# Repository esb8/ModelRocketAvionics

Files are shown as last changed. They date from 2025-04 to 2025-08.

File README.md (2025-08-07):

# Model Rocketry Flight Computer and Embedded Patch Antenna – Full PCB + Assembly

An open-source avionics system developed for **model rocketry** applications by the [Metropolitain Aerospace Rocket Society at Toronto Metropolitan University](https://marstmu.com/). Originally designed for FPV drones, this project has been adapted into a **flight computer** supporting GPS, sensor fusion, data logging, and telemetry, all within a compact, custom PCB. This board also features a **custom microstrip antenna** designed by [Javezki](https://github.com/Javezki). All schematics and KiCad 9.0 PCB design files are openly available.

---

## Overview

This project delivers a robust and flexible **flight computer** for **high-power G-80 model rockets**, built on the STM32F411CEU6 microcontroller. It provides modular avionics functionality—combining flight control, telemetry, power management rated for 1S-2S LiPo, and sensor integration—making it suitable for in-flight data acquisition, staging logic, and recovery system deployment.

---

## Hardware Overview

### **Integrated Flight Computer Design**
- **Flight Computer**: RP2040 
- **Power Regulation**: High-efficiency DC-DC converters (1S LiPo)
- **Telemetry**: Long-range LoRa communication
- **Sensor Suite**: Altitude, attitude, temperature, and pressure sensing

### **Interfaces & Expansion**
- SPI-connected sensor peripherals
- USB-C programming and data offloading
- JTAG/SWD debug support
- UART/FTDI interface for external modules
- Coin cell backup power for RTC
- GPS module for position logging

---

## Flight Computer Board Features

- **MCU**: RP2040 (100MHz ARM Cortex-M4)
- **Clock Source**: 12MHz external crystal
- **IMU**: ICM-42605 (gyro + accel)
- **Barometer**: BMP280 for altitude tracking
- **GNSS**: L86-M33 GPS module (GLONASS+GPS)
- **Telemetry**: SX1276 LoRa 915MHz transceiver (NiceRF)
- **Power**: USB-C input, LDOs, and external 3.3V support

---

## Power System (Planned for Rocket Integration)

- SWD Flash for in-field reprogramming
- High-efficiency DC-DC converters
- Battery support: 1-2S LiPo or custom packs
- Regulated 3.3V rail for sensitive components
- XT60 or JST input connector options

---

## Software Compatibility

- **BetaFlight** (legacy; for IMU prototyping)
- **Custom C/C++ Firmware** (recommended for real-time rocketry logic)

---

## Bill of Materials (Key Components)

| Component | Description | Specification |
|---|---|---|
| Frame | Enclosure/Avionics Bay | Custom 3D-printed or machined |
| MCU | STM32F411CEU6 | ARM Cortex M4 100MHz |
| GPS | L86-M33 | GNSS Positioning |
| IMU | ICM-42605 | 6DOF motion tracking |
| Barometer | BMP280 | Pressure & altitude sensor |
| Radio | SX1276 LoRa | 915MHz telemetry |
| Battery | LiPo / Rocket battery pack | 1S–2S supported via DC regulation |
| Connectors | USB-C, JST, XT60 | Power + Programming |
| Antenna | SMA 915MHz | Half-dipole LoRa |

---

## Tools & Assembly Requirements

- Soldering iron + fine solder
- Heat shrink tubing
- Multimeter & continuity tester
- LiPo battery charger (if applicable)
- Debug tools: ST-Link V2 / J-Link
- KiCad (PCB design and modification)
- Screws, standoffs, foam tape, zip ties

---

## Required Knowledge

- Soldering and PCB assembly
- STM32 microcontroller basics
- Familiarity with LoRa/telemetry systems
- Firmware flashing and serial debugging
- Understanding model rocketry avionics architecture

---

## Calculations

### Altimeter/Flight Timing Logic
- Barometer resolution: ±1 meter (BMP280)
- GPS fix interval: 1Hz–10Hz (L86-M33)
- IMU update: Up to 1kHz via SPI

### Power Budget
- MCU current draw: ~50mA
- LoRa TX Peak: ~120mA
- Sensors + GPS: ~30–50mA
- Total ~200–250mA @ 3.3V (0.7–1W typical)

---

## Testing & Validation

1. Flash microcontroller via SWD
2. USB-C serial communication verification
3. IMU and GPS data output test
4. Barometer altitude validation
5. LoRa telemetry range and signal integrity
6. Full ground simulation test (power cycling, resets)
7. Field tests (static fire or live launch)

---

## Media

### Flight Computer – 3D Model

### Flight Computer – PCB

### Flight Computer – Schematic


## Collaboration

This system is being developed by **Evan Bhogal** and **Javezki** for the **Metropolitan Aerospace Rocket Society at TMU** for use in high-power rocketry and avionics research.

---

## License

Released under the **MIT License**. All PCB files, schematics, and firmware modifications are open source and may be reused and modified with appropriate attribution.

---

## Resources

- [Metropolitan Aerospace Rocket Society](https://marstmu.com)
- [Javezki Github](https://github.com/Javezki)
- [ESB8 GitHub](https://github.com/esb8)
  
---

*This avionics platform bridges the gap between custom hardware and flight-ready model rocketry systems, enabling high-altitude data logging, telemetry, and robust in-flight control capabilities.*

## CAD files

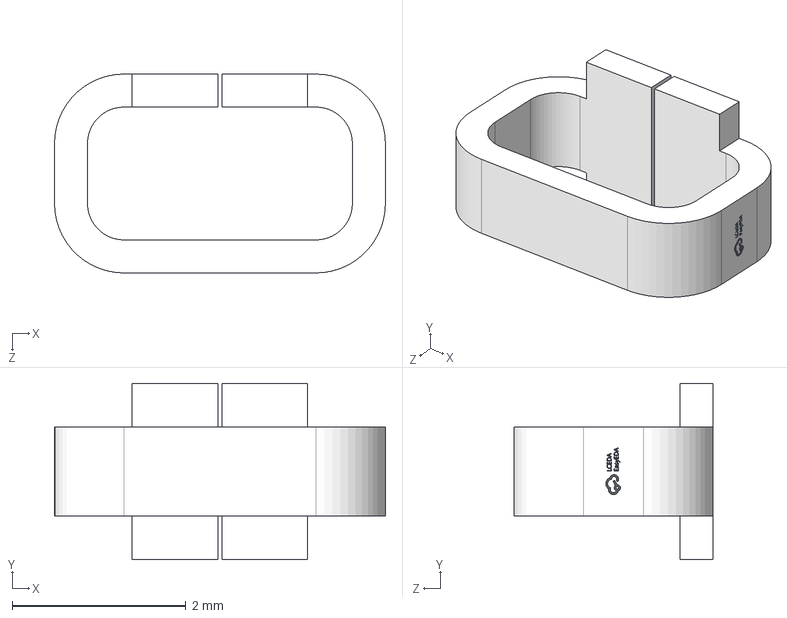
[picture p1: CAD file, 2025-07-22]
Connectors&Switches/5019/CONN-SMD_5019.step
3.81 x 2.03 x 2.29 mm

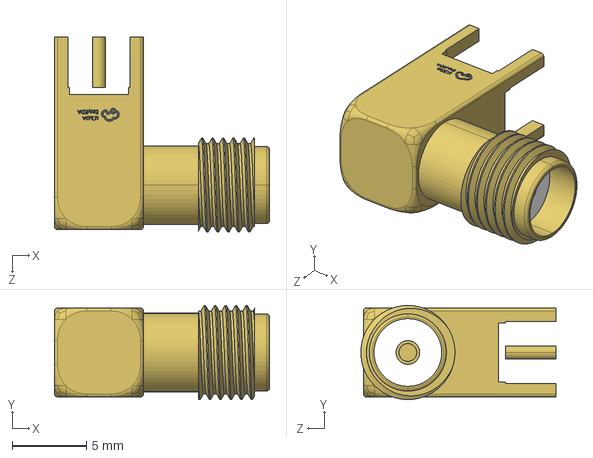
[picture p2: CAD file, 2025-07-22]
Connectors&Switches/SMA/SMA-TH_5P-L14.5-W6.0-H9.6_BWSMA-KWE-Z001.step
14.5 x 6.35 x 13.2 mm

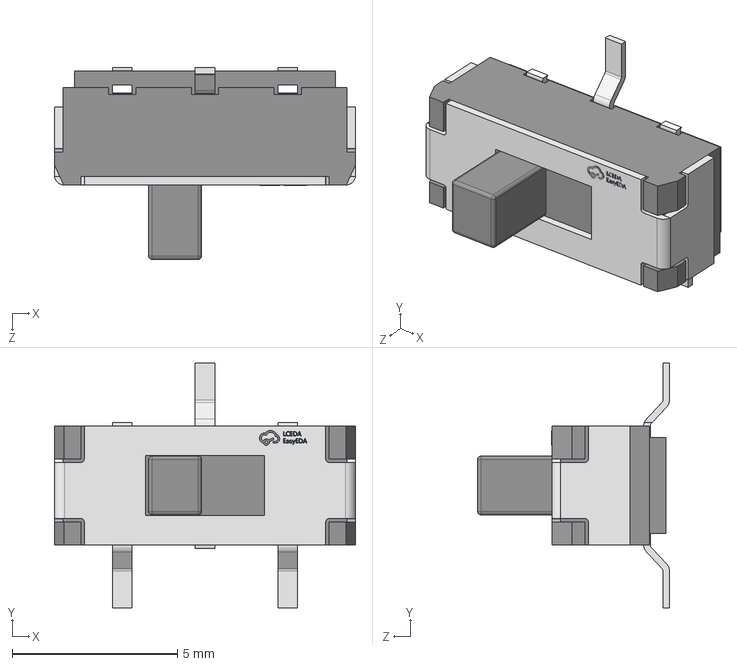
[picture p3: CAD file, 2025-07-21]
Connectors&Switches/SW-SHOUHAN_MST-22D18G23J_C2875122/SW-SMD_SHOUHAN_MST-22D18G23J_C2875122.step
9.10 x 7.40 x 5.80 mm

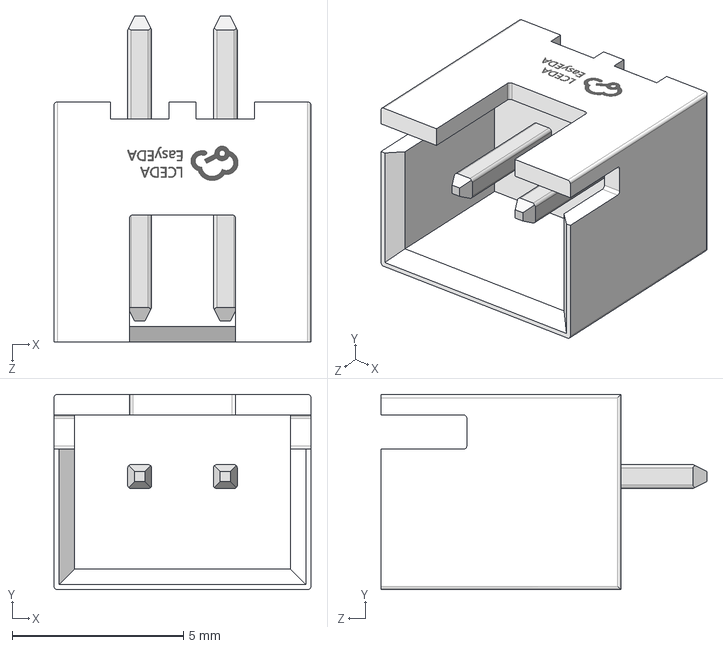
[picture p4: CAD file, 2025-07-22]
Connectors&Switches/XH2.5-2A/XH2.5-2A.step
7.50 x 5.70 x 9.50 mm

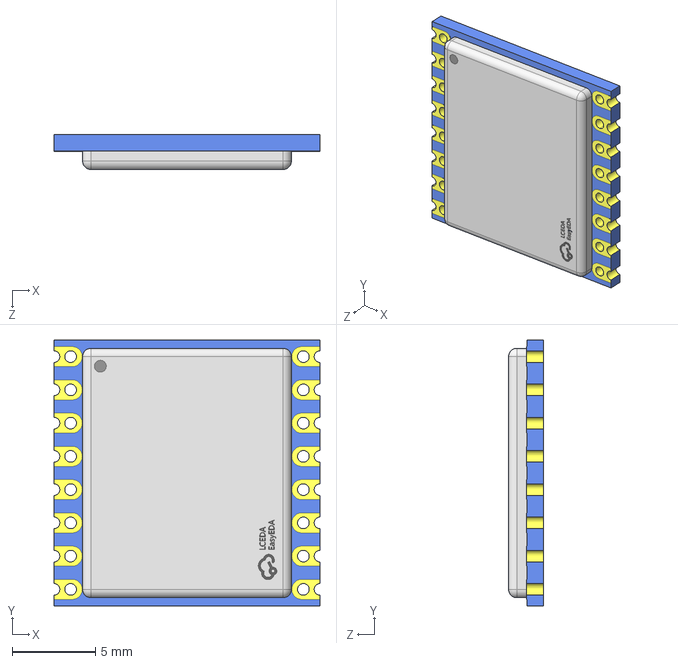
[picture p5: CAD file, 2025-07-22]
ICs/G-NiceRF lora1276-C1-915MHz/COMM-SMD_LORA1276-C1-915MHZ.step
16.0 x 16.0 x 2.12 mm

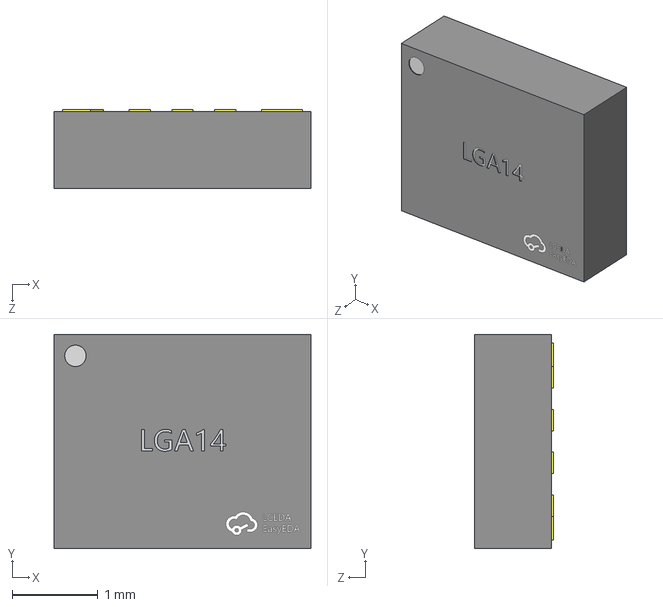
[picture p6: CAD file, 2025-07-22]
ICs/ICM-42605/LGA-14_L2.5-W3.0-H0.9-P0.50.step
3.00 x 2.50 x 0.921 mm

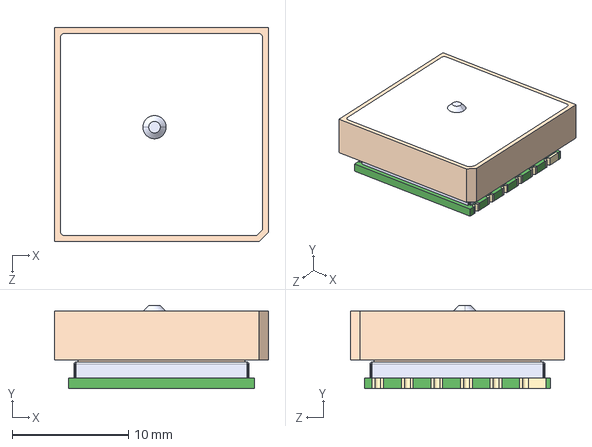
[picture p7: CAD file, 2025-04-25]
ICs/L86/L86-M33.step
18.4 x 7.15 x 18.4 mm

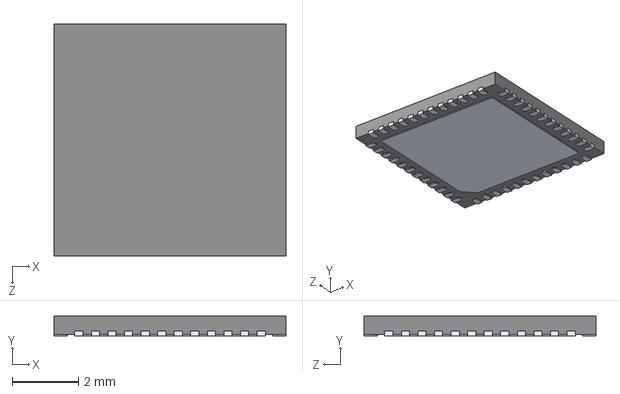
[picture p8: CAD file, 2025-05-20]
ICs/STM32/STM32F411CEU6--3DModel-STEP-56544.STEP
7.00 x 0.6 x 7.00 mm

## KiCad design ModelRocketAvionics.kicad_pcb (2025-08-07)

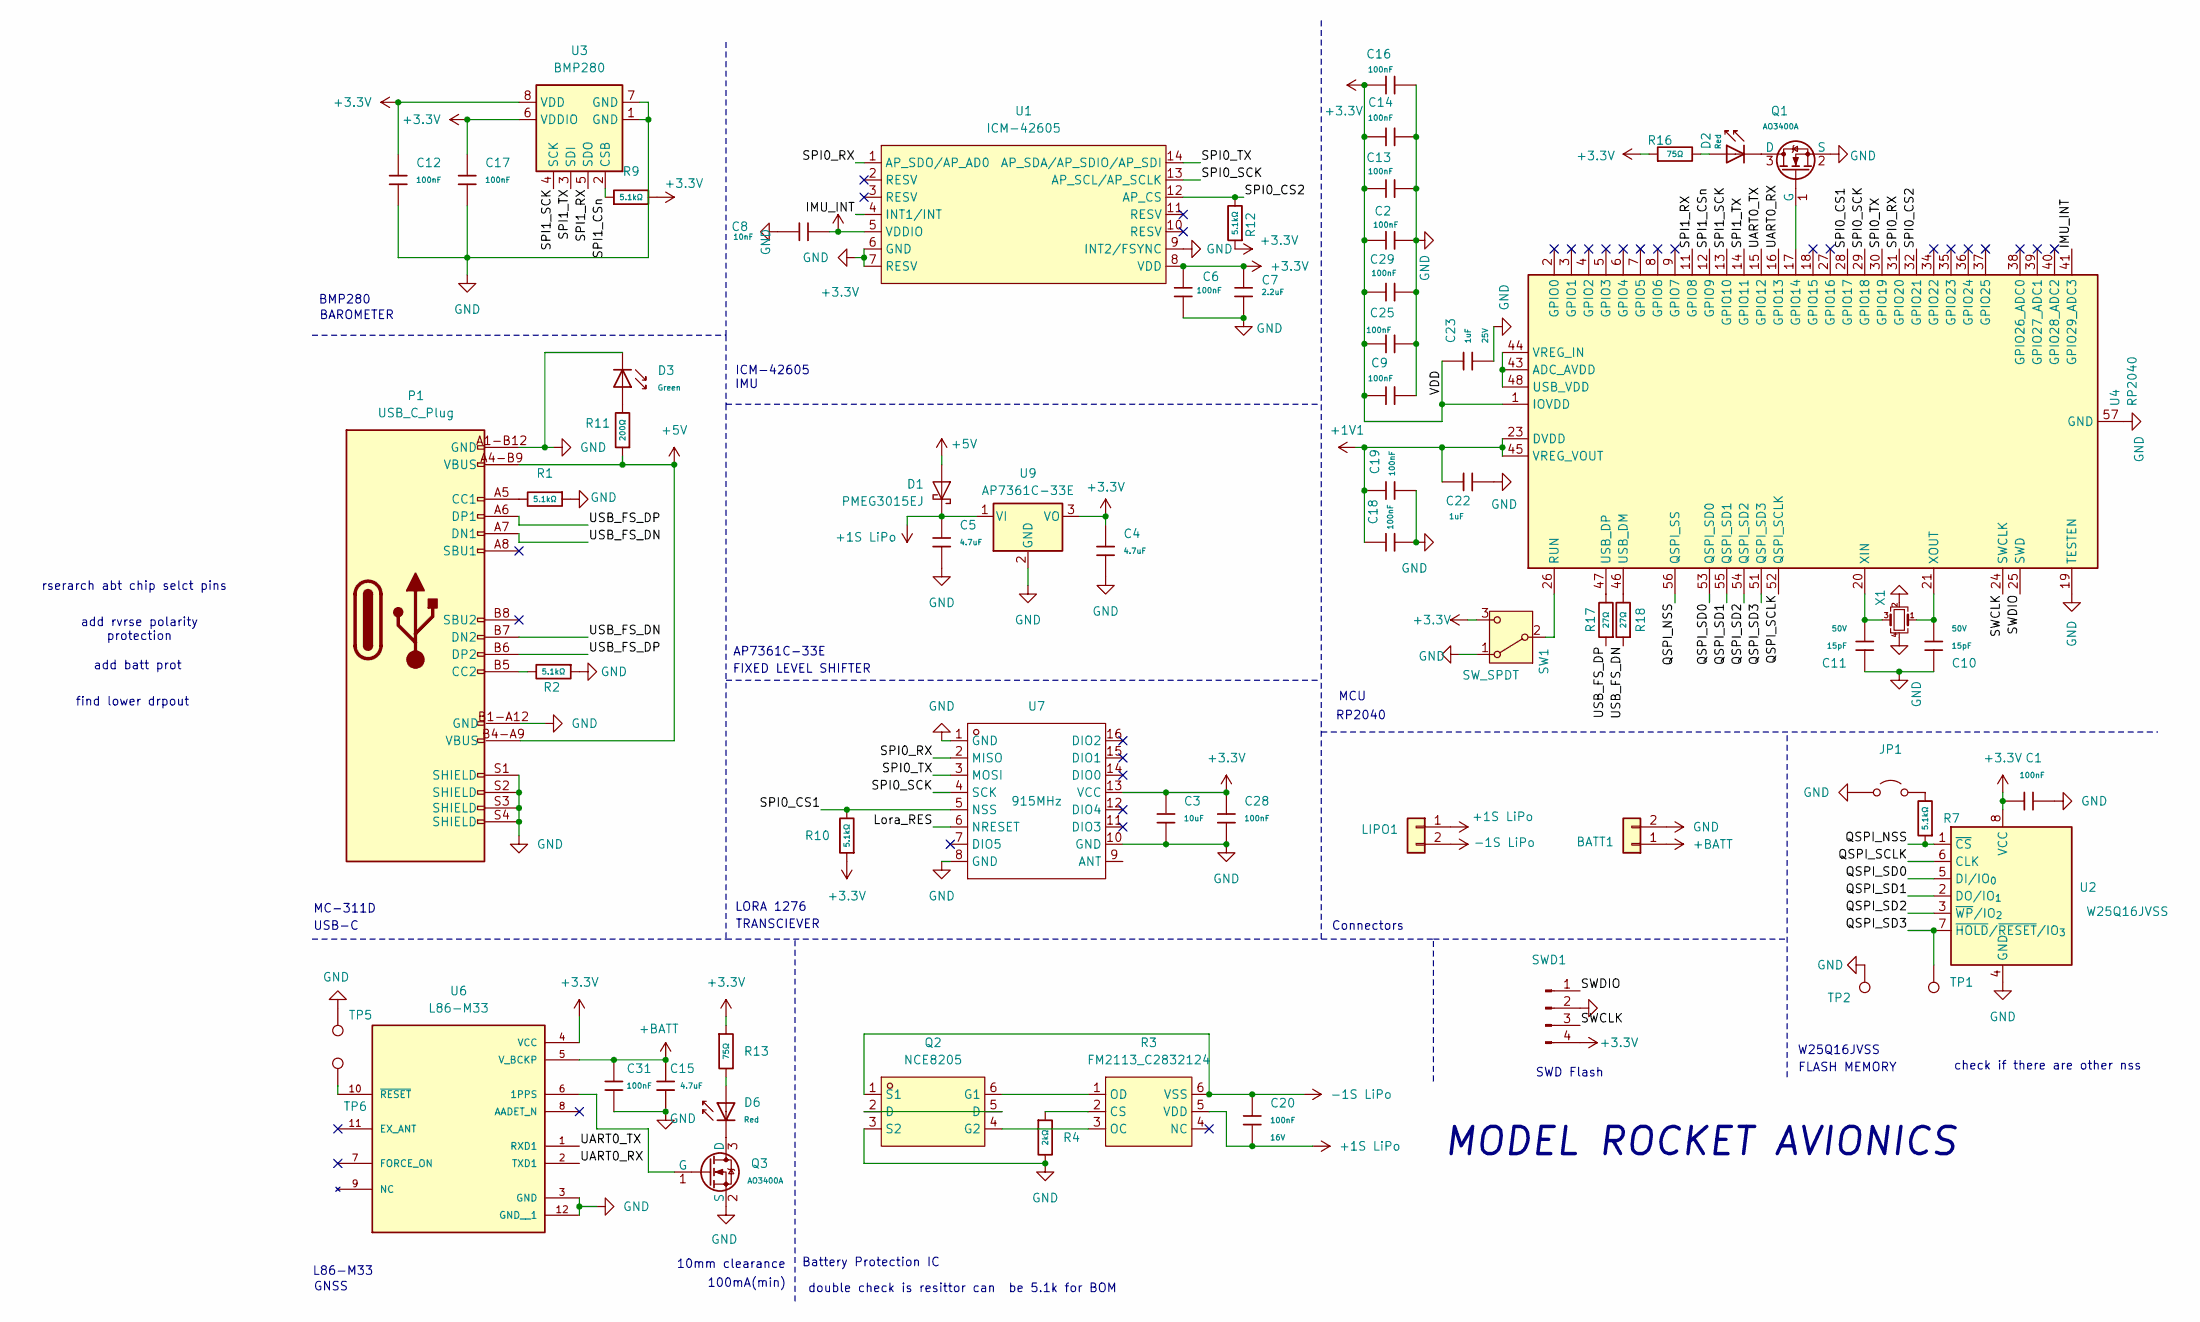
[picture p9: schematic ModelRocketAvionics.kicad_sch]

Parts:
BATT1: Connector; CONN-TH_B2B-XH-A-LF-SN; LCSC Part Number C158012
C1, C2, C6, C9, C12, C13, C14, C16, C17, C18, C19, C25, C28, C29, C31: 100nF; C_0402; Voltage Rated 16V; Tolerance ±10%; Part CL05B104KO5NNNC; LCSC Part Number C1525
C3: 10uF; C_0402; Voltage Rated 6.3V; Tolerance ±20%; Part CL05A106MQ5NUNC; LCSC C15525
C4, C5, C15: 4.7uF; C_0402; Voltage Rated 10V; Tolerance ±20%; Part CL05A475MP5NRNC; LCSC Part Number C23733
C7: 2.2uF; C_0402; Voltage Rated 10V; Tolerance ±10%; Part CL05A225MQ5NSNC; LCSC Part Number C2999759
C8: 10nF; C_0402; Voltage Rated 50V; Tolerance ±10%; Part CL05B103KB5NNNC; LCSC Part Number C15195
C10, C11: 15pF; C_0402; Voltage Rated 50V; Tolerance ±5%; Part 0402CG150J500NT; LCSC C1548
C20: 100nF; C_0402; Voltage Rated 16V; Tolerance ±10%; Part CL05B104KO5NNNC; LCSC C1525
C22, C23: 1uF; C_0402; Voltage Rated 25V; Tolerance ±10%; Part CL05A105KA5NQNC; LCSC C52923
D1: PMEG3015EJ; D_SOD-323F; LCSC Part Number C32798641
D2, D6: Red; D_0805; Forward Voltage (VF) 1.6V~2.6V; Part NCD0805R1; LCSC Part Number C84256
D3: Green; D_0805; Part KT-0805G; LCSC Part Number C2297
JP1: Jumper_2_Open
LIPO1: Connector; CONN-TH_B2B-XH-A-LF-SN; LCSC Part Number C158012
P1: USB_C_Plug; USB_C_Receptacle_GCT_USB4105-xx-A_16P_TopMnt_Horizontal; LCSC Part Number C136423
Q1, Q3: AO3400A; Q_SOT-23; Part AO3400A; LCSC Part Number C20917
Q2: NCE8205; SOT-23-6_L2.9-W1.6-P0.95-LS2.8-BL; LCSC Part C502858
R1, R2, R7, R9, R10, R12: 5.1kΩ; R_0402_1005Metric; Overload Voltage (Max) 50V; Tolerance ±1%; Part 0402WGF5101TCE; LCSC Part Number C25905
R3: FM2113_C2832124; SOT-23-6_L2.9-W1.6-P0.95-LS2.8-BR; LCSC Part C2832124
R4: 2kΩ; R_0402; Overload Voltage (Max) 50V; Tolerance ±1%; Part 0402WGF2001TCE; LCSC C4109
R11: 200Ω; R_0402_1005Metric; Overload Voltage (Max) 50V; Tolerance ±1%; Part 0402WGF2000TCE; LCSC Part Number C25087
R13, R16: 75Ω; R_0603_1608Metric; Overload Voltage (Max) 75V; Tolerance ±1%; Part 0603WAF750JT5E; LCSC Part Number C4275
R17, R18: 27Ω; R_0603; Overload Voltage (Max) 75V; Tolerance ±1%; Part 0603WAF270JT5E; LCSC C25190
SW1: SW_SPDT; SW-SMD_SHOUHAN_MST-22D18G23J_C2875122; LCSC Part Number C2875122
SWD1: Conn_01x04_Pin; PinHeader_2x02_P2.00mm_Vertical; LCSC Part Number C541858
TP1, TP2, TP5, TP6: TestPoint
U1: ICM-42605; LGA-14_L3.0-W2.5-P0.50-TL; LCSC Part Number C2655099
U2: W25Q16JVSS; SOIC-8_5.3x5.3mm_P1.27mm; LCSC Part Number C131025
U3: BMP280; Bosch_LGA-8_2x2.5mm_P0.65mm_ClockwisePinNumbering; LCSC Part Number C83291
U4: RP2040; QFN-56-1EP_7x7mm_P0.4mm_EP3.2x3.2mm
U6: L86-M33; XCVR_L86-M33; Digikey Part Number 2958-L86-M33CT-ND
U7: 915MHz; COMM-SMD_LORA1276-C1-915MHZ; LCSC Part Number C3001531
U9: AP7361C-33E; SOT-223-3_TabPin2; LCSC Part Number C500795
X1: Crystal_GND24_Small; Crystal_SMD_3225-4Pin_3.2x2.5mm; LCSC C20625731

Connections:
+1S LiPo: C5.1, C20.2, D1.1 (K), LIPO1.1, R3.5 (VDD), U9.1 (VI)
+1V1: C18.1, C19.1, C22.1, U4.23 (DVDD), U4.45 (VREG_VOUT), U4.50 (DVDD)
+3.3V: C1.2, C2.1, C3.1, C4.1, C6.2, C7.1, C8.2, C9.1, C12.1, C13.1, C14.1, C16.1, C17.1, C23.1, C25.1, C28.1, C29.1, R9.2, R10.1, R12.1, R13.1, R16.1, SW1.3 (C), SWD1.4, U1.5 (VDDIO), U1.8 (VDD), U2.8 (VCC), U3.6 (VDDIO), U3.8 (VDD), U4.1 (IOVDD), U4.10 (IOVDD), U4.22 (IOVDD), U4.33 (IOVDD), U4.42 (IOVDD), U4.49 (IOVDD), U6.4 (VCC), U7.13 (VCC), U9.3 (VO)
+5V: D1.2 (A), P1.A4-B9 (VBUS), P1.B4-A9 (VBUS), R11.1
+BATT: BATT1.1, C15.1, C31.1, U6.5 (V_BCKP)
-1S LiPo: C20.1, LIPO1.2, Q2.1 (S1), R3.6 (VSS)
/IMU_INT: U1.4 (INT1/INT), U4.41 (GPIO29_ADC3)
/Lora_RES: U7.6 (NRESET)
/QSPI_NSS: R7.1, U2.1 (~CS), U4.56 (QSPI_SS)
/QSPI_SCLK: U2.6 (CLK), U4.52 (QSPI_SCLK)
/QSPI_SD0: U2.5 (DI/IO_{0}), U4.53 (QSPI_SD0)
/QSPI_SD1: U2.2 (DO/IO_{1}), U4.55 (QSPI_SD1)
/QSPI_SD2: U2.3 (~WP/IO_{2}), U4.54 (QSPI_SD2)
/QSPI_SD3: TP1.1, U2.7 (~HOLD/~RESET/IO_{3}), U4.51 (QSPI_SD3)
/SPI0_CS1: R10.2, U4.28 (GPIO17), U7.5 (NSS)
/SPI0_CS2: R12.2, U1.12 (AP_CS), U4.32 (GPIO21)
/SPI0_RX: U1.1 (AP_SDO/AP_AD0), U4.31 (GPIO20), U7.2 (MISO)
/SPI0_SCK: U1.13 (AP_SCL/AP_SCLK), U4.29 (GPIO18), U7.4 (SCK)
/SPI0_TX: U1.14 (AP_SDA/AP_SDIO/AP_SDI), U4.30 (GPIO19), U7.3 (MOSI)
/SPI1_CSn: R9.1, U3.2 (CSB), U4.12 (GPIO9)
/SPI1_RX: U3.5 (SDO), U4.11 (GPIO8)
/SPI1_SCK: U3.4 (SCK), U4.13 (GPIO10)
/SPI1_TX: U3.3 (SDI), U4.14 (GPIO11)
/SWCLK: SWD1.3, U4.24 (SWCLK)
/SWDIO: SWD1.1, U4.25 (SWD)
/UART0_RX: U4.16 (GPIO13), U6.2 (TXD1)
/UART0_TX: U4.15 (GPIO12), U6.1 (RXD1)
/USB_FS_DN: P1.A7 (DN1), P1.B7 (DN2), R18.1
/USB_FS_DP: P1.A6 (DP1), P1.B6 (DP2), R17.1
GND: BATT1.2, C1.1, C2.2, C3.2, C4.2, C5.2, C6.1, C7.2, C8.1, C9.2, C10.1, C11.1, C12.2, C13.2, C14.2, C15.2, C16.2, C17.2, C18.2, C19.2, C22.2, C23.2, C25.2, C28.2, C29.2, C31.2, D3.1, JP1.1 (A), P1.A1-B12 (GND), P1.B1-A12 (GND), P1.S1 (SHIELD), P1.S2 (SHIELD), P1.S3 (SHIELD), P1.S4 (SHIELD), Q1.2 (S), Q2.3 (S2), Q3.2 (S), R1.1, R2.1, R4.2, SW1.1 (A), SWD1.2, TP2.1, TP5.1, U1.6 (GND), U1.7 (RESV), U1.9 (INT2/FSYNC), U2.4 (GND), U3.1 (GND), U3.7 (GND), U4.19 (TESTEN), U4.57 (GND), U6.3 (GND), U6.12 (GND__1), U7.1 (GND), U7.8 (GND), U7.10 (GND), U9.2 (GND), X1.2, X1.4
unnamed: D2.2, R16.2
unnamed: D3.2, R11.2
unnamed: D6.2, R13.2
unnamed: JP1.2 (B), R7.2
unnamed: P1.A5 (CC1), R1.2
unnamed: P1.B5 (CC2), R2.2
unnamed: D2.1, Q1.3 (D)
unnamed: Q1.1 (G), U4.17 (GPIO14)
unnamed: Q2.2 (D), Q2.5 (D)
unnamed: Q2.6 (G1), R3.1 (OD)
unnamed: Q2.4 (G2), R3.3 (OC)
unnamed: D6.1, Q3.3 (D)
unnamed: Q3.1 (G), U6.6 (1PPS)
unnamed: R3.2 (CS), R4.1
unnamed: SW1.2 (B), U4.26 (RUN)
unnamed: U4.43 (ADC_AVDD), U4.44 (VREG_IN), U4.48 (USB_VDD)
unnamed: R18.2, U4.46 (USB_DM)
unnamed: R17.2, U4.47 (USB_DP)
unnamed: C11.2, U4.20 (XIN), X1.3
unnamed: C10.2, U4.21 (XOUT), X1.1
unnamed: TP6.1, U6.10 (~RESET)

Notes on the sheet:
TRANSCIEVER
FLASH MEMORY
MODEL ROCKET AVIONICS
ICM-42605
L86-M33
double check is resittor can be 5.1k for BOM
IMU
add batt prot
MC-311D
SWD Flash
100mA(min)
AP7361C-33E
FIXED LEVEL SHIFTER
BAROMETER
Connectors
Battery Protection IC
USB-C
check if there are other nss
10mm clearance
BMP280
rserarch abt chip selct pins
RP2040
add rvrse polarity protection
GNSS
MCU
W25Q16JVSS
find lower drpout
LORA 1276

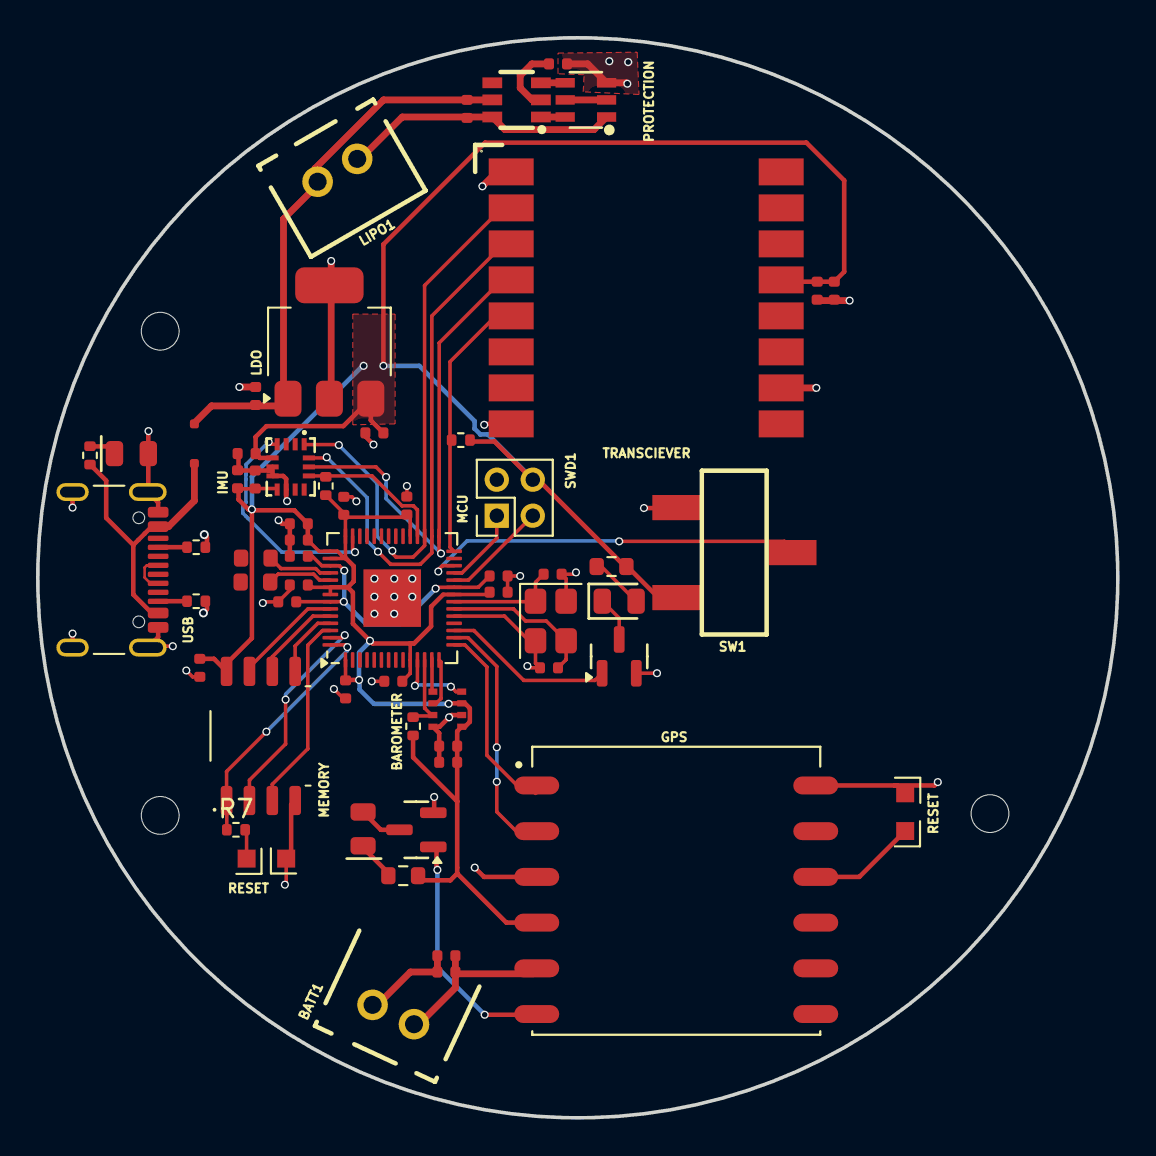
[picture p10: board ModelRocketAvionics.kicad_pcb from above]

Board: 4 copper layers, 60.0 x 60.0 mm, 59 parts (0 on the bottom side), 48 nets.

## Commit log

2025-03-31 V0.1 Schematic
    [DroneController.kicad_pcb, DroneController.kicad_sch]
2025-04-01 Changed I2C to SPI (4Wire) switched IMU, need to add decoupling capacitors and fix GPS
    [DroneController.kicad_sch]
2025-04-02 Added Capacitors
    [DroneController.kicad_sch]
2025-04-05 testing webhooks
    [DroneController.kicad_sch]
2025-04-05 testing webhooks #2
    [DroneController.kicad_sch]
2025-04-06 push power system MP2307DN
    [powerdistrubutionboard.kicad_pcb, powerdistrubutionboard.kicad_sch]
2025-04-06 Added Buck Converter
    [DroneController.kicad_sch]
2025-04-07 Finalized sensor board schematic
    [DroneController.kicad_sch]
2025-04-07 Added basic components
    [ESC_Board.kicad_pcb, ESC_Board.kicad_sch]
2025-04-25 Updated GPS and Buck Converter
    [DroneController.kicad_sch, ESC_Board.kicad_pcb, ESC_Board.kicad_sch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]
2025-04-28 Changed MCU to be compatible with AM32, added Half Bridge driver and sensor circuitry
    [ESC_Board.kicad_sch]
2025-05-03 Started PCB Design
    [DroneController.kicad_pcb, DroneController.kicad_sch]
2025-05-18 Updated STM32 and overhauled SPI wiring, added external flash memory, added LoRa Transciever, moved buck converter to ESC-Board which will handle power distrubution, signficant progress on PCB design.
    [DroneController.kicad_pcb, DroneController.kicad_sch, ESC_Board.kicad_sch]
2025-05-20 Finalized PCB Design
    [DroneController.kicad_pcb, DroneController.kicad_sch]
2025-05-20 Added 3D Models, Changes to Copper Zone, Added Crystal Oscillator to PCB.
    [DroneController.kicad_pcb, DroneController.kicad_sch, MPU-6500--3DModel-STEP-1.STEP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]
2025-05-26 added mounting holes
    [DroneController.kicad_pcb]
2025-05-26 Added LCSC Part Numbers
    [DroneController.kicad_pcb, DroneController.kicad_sch]
2025-05-26 Updated DRC requirements, footprints, and board stackup for impedance management
    [DroneController.kicad_pcb]
2025-06-29 added pull-up resistors, added keepout zones.
    [DroneController.kicad_pcb, DroneController.kicad_sch]
2025-07-04 Fixed GPS wiring
    [DroneController.kicad_pcb, DroneController.kicad_sch]
2025-07-10 DroneController: Improved clarity of silkscreen and added manual reset test pad for the MCU.
    ESC Board: Modified Buck Converter, added SWD debugging, added ICs for BLDC control
    [DroneController.kicad_pcb, DroneController.kicad_sch, ESC_Board.kicad_sch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]
2025-07-11 ESC Board: added mosfets and BackEMF circuitry
    [DRB0008J.stp, ESC_Board.kicad_sch]
2025-07-13 ESC Board: Finalized ESC design
    [ESC1.kicad_sch, ESC_Board.kicad_sch]
2025-07-15 Began PCB design
    [ESC1.kicad_sch, ESC_Board.kicad_pcb]
2025-07-15 Added UART debugging for DroneController, repecced crystal oscillator.
    [DroneController.kicad_pcb, DroneController.kicad_sch]
2025-07-17 DroneController: Adjusted crystal oscillator, added SWD debugging
    [DroneController.kicad_sch, ESC_Board.kicad_pcb, ESC_Board.kicad_sch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]
2025-07-19 Fixed wiring, Added pull-up on CS, respecced IMU, began work on a new layout
    [DroneController.kicad_pcb, DroneController.kicad_sch]
2025-07-20 Finalized PCB and layout of MKII of Drone Controller
    [DroneController.kicad_pcb, DroneController.kicad_sch]
2025-07-21 Finalized MK II of drone controller, added 3D models, followed PCBWay DRC.
    [BOM_DroneController_Final.csv, DroneController.kicad_pcb, DroneController.kicad_sch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]
2025-07-22 Cleaned up repo directory.
    [COMM-SMD_LORA1276-C1-915MHZ.step, CONN-SMD_5019.step, DroneController.kicad_pcb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]
2025-07-22 Basic layout and routing, modified schematic, and directory
    [BOM_DroneController_Final.csv, DRB0008J.stp, DroneController.kicad_pcb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]
2025-07-29 Added more room for antenna pin on LoRa
    [ModelRocketAvionics.kicad_pcb, ModelRocketAvionics.kicad_sch]
2025-08-05 Added RP2040 compatible branch, addded battery protection circuitry
    [ModelRocketAvionics.kicad_pcb, ModelRocketAvionics.kicad_sch]
2025-08-06 Overhauled layout, added more clearance for antenna.
    [ModelRocketAvionics.kicad_pcb, ModelRocketAvionics.kicad_sch]
2025-08-07 Fixed layout of Schematic and pin labelling.
    [ModelRocketAvionics.kicad_pcb, ModelRocketAvionics.kicad_sch]
